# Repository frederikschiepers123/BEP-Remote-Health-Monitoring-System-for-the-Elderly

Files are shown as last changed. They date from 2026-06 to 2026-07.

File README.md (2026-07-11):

# Remote Health Monitoring System for the Elderly

TU Delft BSc Applied Project (BAP). A three-tier system that passively monitors
an elderly person at home — mmWave radar vitals (heart/breath rate, presence),
environment, air quality, light — and delivers the data to a hospital-side
FHIR R4 endpoint, with a smart-mirror UI in the home:

```
┌──────────────────┐   MQTT/mTLS   ┌──────────────────────┐   MQTT/mTLS   ┌──────────────┐   FHIR R4   ┌──────────┐
│  Sensor module   │ ────────────► │  Android tablet      │ ◄──────────── │  SBC         │ ──────────► │ Hospital │
│  Pico 2 W (C11)  │               │  Mosquitto broker    │               │  aggregator  │             │ endpoint │
│  radar/env/air/  │               │  + MagicMirror² UI   │               │  (Python,    │             │ (HAPI in │
│  light + OLED    │               │  behind the mirror   │               │  sbc/)       │             │  dev)    │
└──────────────────┘               └──────────────────────┘               └──────────────┘             └──────────┘
```

Every byte between tiers is mTLS-encrypted (ECDSA P-256, project CA, static
factory-provisioned certs). The firmware publishes raw JSON samples on
`rmms/<uuid>/...`; the mirror and the SBC are independent subscribers of the
same topics.

## Read this first (in order)

1. **[`CLAUDE.md`](CLAUDE.md)** — the firmware + system architecture contract.
   Single source of truth; everything else defers to it.
2. **[`docs/CLAUDE_tablet.md`](docs/CLAUDE_tablet.md)** — the tablet tier
   (broker, MagicMirror², mDNS, presence→screen coupling, autostart).
3. **[`sbc/CLAUDE.md`](sbc/CLAUDE.md)** — the SBC aggregator / FHIR tier.
4. **[`docs/handover.md`](docs/handover.md)** — what is hardware-proven vs
   built-only, known hardware/network gotchas, and CA/cert custody.

## Repository map

| Path | What it is |
|---|---|
| `CLAUDE.md`, `DEMO.md` | The architecture contract and the end-to-end demo runbook (see reading order above / quickstarts below). |
| `main/`, `components/` | **Pico 2 W firmware** (C11; pico-sdk + FreeRTOS + lwIP/mbedTLS + littlefs). One component per concern — layout in `CLAUDE.md §6`. |
| `test/host/` | Native unit tests (CMocka) for driver logic — `bash test/host/run.sh`. |
| `test/bringup/` | Standalone bring-up/diagnostic firmware images (blink → sensors → Wi-Fi → mTLS → full bench). `bringup_sensors` is the demo image. |
| `docs/` | System docs: bring-up procedure, MQTT topic contract, pin map, ADRs, provisioning, handover, technical audit of the previous group's code. |
| `scripts/` | Operational scripts: build, CA + device provisioning, tablet deploy/boot, demo startup, broker ACL test. Index: `scripts/README.md`. |
| `sbc/` | **SBC aggregator** — standalone Python project (own README, RUNBOOK, CLAUDE.md, tests). Never compiled into the firmware. |
| `MagicMirror/` | Vendored upstream MagicMirror² tree (see its README). Project work lives only in `modules/MMM-SensorUI/`, `modules/MMM-CustomMQTTBridge/`, `css/`, `config/` — the live `config.js` holds LAN specifics, is gitignored, and lives on the tablet; `config/config.custom.sample.js` is a UI-only starter. |
| `HealthMonitorWakeTest/` | **Android wake app** (Android Studio project): radar presence ↔ tablet screen on/off via the localhost MQTT listener (ADR-0004). See its README. |
| `apk/` | Prebuilt APK of the wake app. |
| `fully/` | Exported settings for the optional Fully Kiosk Browser (mirror kiosk mode). |
| `third_party/` | Git submodules: FreeRTOS-Kernel, littlefs. **pico-sdk is not vendored** — see the firmware quickstart. |
| `documents_and_diagrams/` | Thesis report, defense presentation, system diagrams. |
| `papers/` | Reference papers + the complete reference list. |
| `lasercutting_files/` | Enclosure/acrylic lasercutting files (DXF + Fusion 360). |
| `PCB/` | This group's KiCad PCB design files + bench measurements (buck converter scope shots). |
| `Readout Code HMMD-MR60BHA2 and BMP/` | Standalone sensor-readout experiments (radar filtering tests, BMP readout) used during bring-up — not part of the production firmware. |

**Local / generated directories (never in git):** `build*/` are CMake output
trees; `out/` is provisioning output created by `scripts/provision_ca.sh` —
it holds device/broker/mirror certificate bundles **including private keys**
and must never be committed (it is gitignored; see `docs/provisioning.md`).
On a fresh clone neither exists until you build/provision.

The **previous BAP group's material** (`bestanden_vorige_BAP/`) was removed
from the tree during handover cleanup — it is reference-only and available in
git history (any pre-July-2026 commit). Their registration protocol was
audited (`docs/technical-audit.md`) and deliberately replaced
(`CLAUDE.md §9.4`); their committed private keys are burned — never reuse
anything cryptographic from that tree.

## Quickstart per tier

### Firmware (Pico 2 W)

```bash
git clone --recurse-submodules <this-repo>            # brings FreeRTOS-Kernel + littlefs
git clone https://github.com/raspberrypi/pico-sdk.git ~/pico/pico-sdk
(cd ~/pico/pico-sdk && git submodule update --init)
export PICO_SDK_PATH=~/pico/pico-sdk

mkdir build && cd build
cmake -DPICO_BOARD=pico2_w -DCMAKE_BUILD_TYPE=Debug ..
cmake --build . -j$(nproc)
# → main/sensor_module.uf2 (production) + test/bringup/*.uf2 (bring-up images)
```

Flash: hold BOOTSEL while plugging in, copy the `.uf2` to the mounted drive
(details + SWD alternative: `CLAUDE.md §5`). Bring-up order with expected
results per step: `docs/bring_up.md`. Host tests: `bash test/host/run.sh`.

### Certificates + device provisioning

Identity is factory-provisioned: certs are generated **off-device** by the
project CA and written to the Pico's littlefs; there is no enrollment protocol
(`CLAUDE.md §9.4`). The full procedure — CA creation, broker/mirror/operator/
device bundles, `bringup_provision.uf2` + `scripts/provision_device.py` — is in
**[`docs/provisioning.md`](docs/provisioning.md)**. The CA private key is *not*
in this repo; custody is covered in `docs/handover.md`.

### Tablet (broker + mirror)

`scripts/deploy_home_kit.sh` provisions/deploys the whole tablet kit over ssh
(Termux); `scripts/tablet_boot.sh` + Termux:Boot make the tablet self-healing
across reboots. Tier spec: `docs/CLAUDE_tablet.md`.

### SBC aggregator (FHIR)

```bash
cd sbc && python3 -m venv .venv && .venv/bin/pip install -e .[dev]
.venv/bin/python -m pytest tests -q
```

Full install/run/prove-the-FHIR-output walkthrough: `sbc/RUNBOOK.md`.

### End-to-end demo

Full session procedure: **[`DEMO.md`](DEMO.md)**. In short:
`scripts/demo_start.sh <tablet-ip>` starts a demo session; a provisioned Pico
running `bringup_sensors.uf2` publishes live sensor data and the mirror renders
it. Networking caveats (use a phone hotspot, not eduroam; keep the tablet
awake) are in `docs/handover.md`.

## Where the contracts live

- MQTT topics + JSON payload schema: `CLAUDE.md §9`, `docs/mqtt_topics.md`.
- Sensor-JSON → FHIR mapping: `CLAUDE.md §9.6` (firmware side) and
  `sbc/docs/fhir-mapping.md` (generated LOINC/UCUM table).
- Mirror UI boundary (raw topics, JS-side thresholds, two-namespace design):
  `CLAUDE.md §9.5`/`§9.5.1` and the module READMEs under `MagicMirror/modules/`.
- Cross-tier loss-tolerance + idempotency: `docs/sbc-failover-and-idempotency.md`.

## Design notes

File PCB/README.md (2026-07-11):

# PCB/

- `PCB Design/` — all KiCad files.
- `Buck_images/` — oscilloscope photos from testing the buck-converter
  circuit on the PCB (directory names give the load condition).

## Which files are authoritative

- **Generic (sensor-module) board:**
  `PCB Design/KiCad files/Generic PCB/Generic PCB/Generic PCB.kicad_pcb`
  (+ matching `.kicad_sch`/`.kicad_pro`). Note the doubled `Generic PCB/`
  nesting is a KiCad project-folder artifact — descend twice.
- **Mirror board:**
  `PCB Design/KiCad files/Mirror PCB/Mrror PCB.kicad_pcb`
  (+ matching `.kicad_sch`/`.kicad_pro`).

Caveats for the next group:

- The `Mrror` spelling is a typo, but it is **load-bearing**: KiCad project
  files cross-reference each other by name — do not rename.
- Some `Mrror PCB*` artifacts (silkscreen PDFs, `Mrror_PCB_routed_v1.kicad_pcb`)
  also sit inside the *Generic* board's folder; the Mirror board's canonical
  files are the ones under `Mirror PCB/`.
- KiCad autosave/backup droppings (`_restore_backup_*`, `*.lck`, `*.bak`,
  `*_chatgpt*.zip`) were deleted at handover and are now gitignored.
- Known board erratum: the I²C bus lacks pull-ups — fit 4.7 kΩ from GP8/GP9
  to 3V3 (see `docs/handover.md`).

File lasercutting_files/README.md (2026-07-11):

# lasercutting_files/

Enclosure/mirror lasercutting sources for the sensor module and the two-way
acrylic mirror front.

- `designing_cuts_acrylic_plates.f3d` — Autodesk Fusion 360 design file (the
  editable source of all cuts).
- `testcuts_radarsensors.dxf` — test cuts, for an acrylic plate of 225×400 mm.
- `finalcut_rounded_rectangle.dxf` — the final cut, for an acrylic plate of
  250×300 mm.

View DXF files without CAD software at <https://dxfviewer.app/>.

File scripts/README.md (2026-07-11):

# scripts/

Operational tooling for the RMMS pipeline — building and provisioning the Pico
sensor module, standing up the Termux tablet tier (Mosquitto broker +
MagicMirror²), and running demos. Each script's header comment is the
authoritative usage doc; this file is only an index.

## Index

| Script | Tier | Purpose |
| --- | --- | --- |
| `build.sh` | firmware | Compile the sensor-module firmware (`build/main/sensor_module.uf2` + `.elf`); optional `--flash` (BOOTSEL) / `--swd` (OpenOCD). Firmware only — no certs, no littlefs content. |
| `provision_ca.sh` | provisioning | Generate the project CA (once) plus broker, mirror, operator, and per-device certs (all ECDSA P-256). CA private key never leaves `$CA_DIR`. |
| `provision_device.py` | provisioning | Push a device bundle (certs + `/cfg` JSON) into the Pico over USB-serial; pairs with the `bringup_provision` UF2, verifies SHA-256 per file, reboots the device. |
| `deploy_home_kit.sh` | provisioning | One-command, idempotent orchestrator for a full home kit (certs → tablet → Pico → SBC), plus a `fleet` mode that loops a TSV manifest. Calls the per-tier tools above. |
| `refresh_broker.sh` | tablet | One-shot broker refresh: re-issue the broker cert for today's tablet IP, scp it to Termux, restart Mosquitto, verify :8883 answers. |
| `setup_tablet_ssh.sh` | tablet | One-time: copy the laptop's SSH public key onto the tablet so `refresh_broker.sh` runs unattended. |
| `tablet_boot.sh` | tablet | Termux:Boot entry point — an Android boot brings up sshd, the broker, the mDNS responder, the presence bridge, and MagicMirror² with no laptop involved. IP-independent and idempotent. |
| `tablet_mdns_responder.py` | tablet | Advertises a stable `tablet.local` name (python-zeroconf, RFC 6762 legacy-unicast) so the Pico finds the broker by name across IP changes. |
| `tablet_presence_screen.py` | tablet | Bridges radar `v.presence` (mTLS `rmms/+/radar`) to the wake/lock app's plain-MQTT `display` topic ("ON"/"OFF") with debounce — screen follows presence. |
| `tablet_start_magicmirror.sh` | tablet | Launches MagicMirror² in server-only mode (`npm run server`), opens Chrome at `localhost:8080`, restarts MM² with backoff if it dies. |
| `demo_start.sh` | demo | One-shot demo bring-up from the laptop: refresh broker cert + restart Mosquitto, start the `tablet.local` mDNS responder, start the radar-presence→screen bridge, refresh the fixed demo-device bundle (first-provision only). MagicMirror runs on the tablet via Termux:Boot — this script does not start it. |
| `test_broker_acl.sh` | demo | Broker mTLS + ACL enforcement harness (7 assertions: own-subtree write, cross-device deny, operator scope, `/cmd` read, anonymous refused). Exit 0 only if all hold. |
| `mock_radxa.py` | SBC | Read-only dev sniffer: subscribe to one device's raw topics, decode the §9.2 envelope, pretty-print values. Its old Radxa-stand-in role is dead — run `sbc/` for real aggregator behaviour. |

`scripts/deprecated/` holds superseded scripts (currently the previous group's
tablet `deploy.sh` and its PDF instructions) — see its own README.

## Typical flows

**Fresh device provisioning**

1. `scripts/provision_ca.sh` — mint (or reuse) the CA and issue the device
   bundle into `out/device-<uuid>/`. For a whole home kit in one go, use
   `scripts/deploy_home_kit.sh` instead — it orchestrates this plus the tablet
   and SBC tiers.
2. Flash the `bringup_provision` UF2, then
   `scripts/provision_device.py /dev/ttyACM0 out/device-<uuid>` to write certs
   and config into littlefs.
3. `scripts/build.sh --flash` (or `--swd`) to build and flash the production
   firmware.

**Demo startup (laptop-driven)**

`scripts/demo_start.sh <tablet-ip>` does the whole session bring-up: broker
cert refresh + Mosquitto restart, `tablet.local` mDNS responder, and the
radar-presence→screen bridge. MagicMirror itself runs on the tablet via
Termux:Boot (`tablet_boot.sh`) and is not started from the laptop. Thanks to
mDNS, the demo Pico is provisioned once and never re-flashed when the IP
changes.

**Tablet self-heal (no laptop)**

`scripts/tablet_boot.sh`, symlinked from `~/.termux/boot/10-rmms`, makes an
Android reboot self-healing: Termux:Boot fires it post-unlock and it restarts
every tablet service, guarded by `pgrep` so double-launches are impossible.
One-time prerequisites (Termux:Boot from F-Droid, battery-optimization off)
are listed in its header.

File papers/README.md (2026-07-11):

- Any references not included in this folder as a pdf (for example websites) are included in the file complete_reference_list.pdf.

- Literature and datasheets about mmwave: Here are the literature about the background study about the using mmwave radar sensors for sensing the vital signs.

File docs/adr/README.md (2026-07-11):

# Architecture Decision Records

Each significant architectural decision is recorded here as a short ADR.

## Format

```
# ADR-NNN: Title

**Status:** Accepted | Superseded by ADR-NNN | Deprecated
**Date:** YYYY-MM-DD

## Context
What forced a decision?

## Decision
What was decided?

## Consequences
What becomes easier or harder?
```

## Index

| # | Title | Status |
|---|---|---|
| [0001](0001-light-sensor-bh1750.md) | Replace GL5516 LDR with Rohm BH1750FVI for ambient light | Accepted |
| [0002](0002-wifi-sole-transport.md) | Wi-Fi is the sole v1 transport — USB-CDC dropped | Accepted |
| [0003](0003-nv-flash-spool-and-time-sync.md) | Non-volatile flash spool + tablet time-sync (lossless uplink) | Accepted |
| [0004](0004-localhost-plain-listener-app-ipc.md) | Localhost-only plain :1883 listener for on-tablet app IPC | Accepted |
| [0005](0005-mcu-side-radar-filtering.md) | MCU-side radar plausibility filtering (supervisor-directed) | Accepted |
| [0006](0006-phase-based-breath-hold-detection.md) | Phase-based breath-hold (apnea) detection (resp_motion) | Accepted |
| [0007](0007-hmmd-radar-second-driver.md) | Second radar driver — Waveshare HMMD 24 GHz behind the v-table | Accepted |
| 0008 | Phase-derived breath rate via Goertzel (no file — see note) | Reverted |
| [0009](0009-led-pin-correction.md) | POWER/WIFI status-LED pins corrected to match the as-built PCB | Accepted |

**ADR-0008 note:** the Goertzel breath-rate estimator landed with commit
`6329d47` and was reverted in `4376965` after bench testing showed it
sub-harmonic-locks to ~half the true rate on real irregular breathing. The
radar's own 0x0A14 breath-rate output is used instead. The number is retired,
not reused; the design and revert rationale live in the git history of those
two commits.

## When to write an ADR

Per CLAUDE.md §4: any new dependency, any change to `board_pico2wh.h`, any new
MQTT topic or command, any change to the security model, or any deviation from
the bring-up order in §15 requires an ADR before the code is written.

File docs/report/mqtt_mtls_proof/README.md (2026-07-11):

# MQTT + mTLS communication — captured proof

Captured 2026-06-21. These logs demonstrate the firmware's MQTT contract
(CLAUDE.md §8.3, §9) and security model (§10) working end to end at the
**protocol level**: mutual-TLS handshake, cert-CN identity, QoS-1 publish/PUBACK,
message delivery to a subscriber, and broker-side ACL enforcement.

## Scope of this capture (read first)

This bundle was produced on the **development host** by running the **real
production broker config** (`out/broker/mosquitto.conf`) with the **real
CA-issued certificates** (`out/`) on the loopback interface, and connecting with
the `mosquitto`/`openssl` clients using the device, mirror and operator certs.

- ✅ Proves: the mTLS trust model, the restricted cipher suite (§10.2),
  `require_certificate`, `use_identity_as_username`, the per-cert ACL, and the
  QoS-1 MQTT round-trip — all with the exact certs and broker policy that ship
  on the tablet.
- ⚠️ Does **not** prove (here): the Pico firmware binary talking to the physical
  tablet over Wi-Fi. That has been demonstrated separately on hardware
  (2026-06-02 `bringup_mqtt.uf2`; 2026-06-19 full PCB e2e on the iPhone hotspot —
  Wi-Fi join, mTLS `CONNACK status=0`, radar vitals publishing). To re-capture
  that live, see "Re-capturing the hardware path" below.

The only differences between `mosquitto-local.conf` and the tablet's
`out/broker/mosquitto.conf` are the cert **paths** (repo `out/` vs Termux home),
the **bind address** (`127.0.0.1` vs `0.0.0.0`), and one extra `log_type
information` line. Auth/TLS/ACL settings are byte-identical.

## Artifacts

| File | What it proves |
|---|---|
| `01_mtls_handshake.log` | Full mutual-TLS handshake as the **device** identity. TLS 1.2, cipher `ECDHE-ECDSA-AES256-GCM-SHA384` (§10.2), `Verify return code: 0 (ok)`, broker chain `tablet.local ← RMMS-Project-CA`, ECDSA peer signature, broker **requested** a client cert (mutual auth). |
| `02_nocert_refused.log` / `02b_nocert_mosquitto.log` | Negative control — a client with **no certificate** is refused (`sslv3 alert handshake failure` / `tlsv13 alert certificate required`). `require_certificate true` enforced. |
| `03_device_publish.log` | Device side of a QoS-1 publish: `CONNECT → CONNACK(0) → PUBLISH(q1) → PUBACK(RC:0)`. |
| `03_mirror_received.log` | Mirror side: the exact §9.2 env JSON delivered over the mirror's own mTLS session. |
| `04_acl_harness.log` | `scripts/test_broker_acl.sh` — **7/7** ACL+mTLS assertions (own-subtree write allowed, cross-device write/read denied, operator info-only, device reads own /cmd, anonymous refused). CLAUDE.md §16-Q9 / bring-up step 12. |
| `broker.stdout.log` | Broker side: each client's MQTT username is its **verified cert CN** (`u'52295a51-…'` = device UUID, `u'mirror-de4ed19a'`, `u'operator-c4c60d23'`) via `use_identity_as_username`; no-cert probes logged as `<unknown> disconnected: Protocol error`. |
| `mosquitto-local.conf` | The localized broker config used for the capture. |

## Reproduce this capture

```bash
# 1. start the broker with the real config + certs on loopback
mosquitto -c docs/report/mqtt_mtls_proof/mosquitto-local.conf -v &

# 2. mTLS handshake as the device
DEV=out/device-52295a51-1a2d-4b2f-bedd-dacbbc1685f0
openssl s_client -connect 127.0.0.1:8883 -CAfile out/broker/ca.crt \
  -cert $DEV/dev.crt.pem -key $DEV/dev.key.pem \
  -verify_ip 127.0.0.1 -verify_return_error \
  -tls1_2 -cipher ECDHE-ECDSA-AES256-GCM-SHA384 </dev/null

# 3. full ACL + mTLS harness
scripts/test_broker_acl.sh 127.0.0.1
```

## Re-capturing the hardware path (Pico → tablet)

When the Pico and tablet are on the same network (phone hotspot — see
project memory; eduroam blocks device↔tablet P2P):

```bash
# device console (TLS handshake → CONNACK → first publish)
minicom -D /dev/ttyACM1 -b 115200          # or: cat /dev/ttyACM1

# on the tablet (or a host with the mirror cert), watch real samples land:
mosquitto_sub --cafile out/broker/ca.crt -h tablet.local -p 8883 \
  --cert out/mirror-*/cert.pem --key out/mirror-*/key.pem \
  -t 'rmms/#' -v
```

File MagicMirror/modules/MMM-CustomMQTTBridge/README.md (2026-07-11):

# MMM-CustomMQTTBridge

Project-internal MagicMirror² module for the TU Delft RMMS (Remote Medical
Monitoring System) BAP project. It is the **adapter between the MQTT wire
contract and the mirror's in-process notification bus**:

- **Wire side** — connects over **mTLS** to the tablet's Mosquitto broker
  (`:8883`) and subscribes to the sensor firmware's raw
  `rmms/<uuid>/<kind>` topics (JSON envelope per root `CLAUDE.md` §9.2).
- **Mirror side** — parses each payload in the `node_helper` and re-broadcasts
  every logical sensor field as an `MQTT_SENSOR_UPDATE` MM² notification with
  payload `{topic: "sensors/<field>", message: "<string>"}`, which
  [`MMM-SensorUI`](../MMM-SensorUI/README.md) consumes.

These are **two deliberately distinct namespaces** (root `CLAUDE.md` §9.5.1):
`rmms/...` is the broker contract shared by the firmware, the Radxa/SBC
aggregator, and the mirror; `sensors/...` exists only inside the MM² process,
between this bridge and MMM-SensorUI. The firmware never emits `sensors/...`;
the tile code never sees `rmms/...` or wire JSON.

> **Repo note:** the surrounding `MagicMirror/` tree is a vendored upstream
> MagicMirror² checkout. Only `modules/MMM-CustomMQTTBridge/`,
> `modules/MMM-SensorUI/`, and the tablet-side `config/` + `css/`
> customisations are project work.

## Single source of truth

This module — specifically the mapping table and dispatch code at the top of
[`node_helper.js`](node_helper.js) — is the **canonical wire→mirror
translation**, referenced by root `CLAUDE.md` §9.5.1. Envelope parsing,
stringification, and null/warm-up handling all live here and nowhere else.
**Adding a new sensor field is a change in exactly one place:** one
`send("name", value)` call in the right `if (kind === ...)` branch of
`node_helper.js`. MMM-SensorUI then only needs a handler for the new
`sensors/<name>` notification; it never touches JSON.

## Configuration

Set in `MagicMirror/config/config.js` (gitignored — the checked-in
`config.js.sample` is the plain upstream sample, not an RMMS example).
Defaults from `MMM-CustomMQTTBridge.js`:

| Key | Default | Meaning |
|---|---|---|
| `broker` | `"mqtts://<tablet-ip>:8883"` | Broker URL. `mqtts://` + all three cert files present ⇒ mTLS; otherwise the bridge falls back to plain MQTT (local mock/test path only). |
| `clientId` | `"mirror-de4ed19a"` | MQTT client ID. **Must match the CN of the mirror certificate** (`mirror-<short-id>`) issued by `scripts/provision_ca.sh` — the broker uses `use_identity_as_username` and its ACL grants the mirror role `topic read rmms/+/+`. |
| `caFile` | `""` | Absolute path to the project CA cert (PEM, from `out/mirror-<id>/`). |
| `certFile` | `""` | Absolute path to the mirror client cert (PEM). |
| `keyFile` | `""` | Absolute path to the mirror private key (PEM). |
| `topics` | `["rmms/+/+"]` | Subscriptions (wildcard covers all devices). |

With TLS active, `rejectUnauthorized: true` is set — server cert validation is
never disabled. The helper keeps **one** MQTT client per process: because the
mirror runs `serveronly`, the browser module re-sends `CONNECT_MQTT` on every
socket reconnect, and without the guard duplicate clients sharing the mirror
`clientId` would kick each other off the broker in a loop.

## Topic → notification mapping

Copied from the canonical table in `node_helper.js`:

| Broker topic + field | Mirror notification | Value (string) |
|---|---|---|
| `rmms/<uuid>/env` · `v.temp_c` | `sensors/temperature` | float, `.toFixed(1)` |
| `rmms/<uuid>/env` · `v.hum_pct` | `sensors/humidity` | int, rounded |
| `rmms/<uuid>/air` · `v.aqi` (1–5) | `sensors/airquality` | UBA label (`Excellent` / `Good` / `Moderate` / `Poor` / `Unhealthy`); `aqi == 0` ⇒ `"WARMUP"` |
| `rmms/<uuid>/air` · `v.co2_ppm` | `sensors/co2` | int |
| `rmms/<uuid>/air` · `v.tvoc_ppb` | `sensors/tvoc` | int |
| `rmms/<uuid>/radar` · `v.heart_bpm` | `sensors/heartrate` | int, rounded; `""` when null |
| `rmms/<uuid>/radar` · `v.breath_bpm` | `sensors/respiratoryrate` | int, rounded; `""` when null |
| `rmms/<uuid>/radar` · `v.resp_motion` | `sensors/respiratorymotion` | `"true"` / `"false"` / `""` (tri-state breath-hold signal, firmware ADR-0006) |
| `rmms/<uuid>/info` · `v.text` | `sensors/infomessage` | text |
| `rmms/<uuid>/status` (raw string, retained) | `sensors/status` | `"online"` / `"offline"` (forwarded for introspection; MMM-SensorUI does not currently display it) |
| `rmms/<uuid>/light` | — | intentionally ignored in v1 |
| `rmms/<uuid>/log` | — | intentionally ignored (not sensor data) |
| `rmms/<uuid>/screen` | — | not mapped in the current code (the operator page-select topic from `CLAUDE.md` §9.5 is not wired through this bridge yet) |

Topics that don't match the `rmms/<uuid>/<kind>` shape are relayed **verbatim**
(topic + raw string), so legacy `sensors/...` test publishers keep working
against local mock setups.

## Null / quality / warm-up handling

What the code actually does:

- **Radar nulls clear the tile.** Firmware vitals are presence-gated: a `null`
  `heart_bpm` / `breath_bpm` means "no presence-confirmed reading". The bridge
  forwards `null` as an **empty string**, which MMM-SensorUI treats as
  "no value" ("Measuring..."), instead of freezing the last number after the
  person walks away. `resp_motion` `null`/absent likewise becomes `""`
  (undetermined — clears any hold state; old firmware without the field is
  therefore harmless).
- **ENS160 warm-up.** Only `aqi == 0` (no usable reading yet) is shown as
  `"WARMUP"`. Readings with `aqi >= 1` are forwarded even while the chip still
  flags `INITIAL_STARTUP` (envelope `q=2`, up to ~1 h) — those values are
  already meaningful.
- **Envelope `q` flag.** Beyond the AQI case above, the current code does
  **not** inspect the envelope's `q` quality field; the firmware itself nulls
  degraded vitals, and that nulling is what the bridge forwards. If `q`-based
  gating is ever needed on the mirror, it belongs **here**, not in
  MMM-SensorUI (per §9.5.1). Note from field experience: gating presence
  behaviour on `distance != null` is more robust than gating on `q`.
- **Non-JSON payloads** on an `rmms/...` topic are logged and dropped.
- The parser tolerates both the `{"ts_us":..., "v":{...}}` envelope and a flat
  object (`env.v || env`).

## Files

- `MMM-CustomMQTTBridge.js` — browser-side module: sends `CONNECT_MQTT` with
  the config, relays `MQTT_SENSOR_UPDATE` onto the MM² notification bus, and
  shows the last message / bridge status as a small debug DOM (header
  "MQTT bridge").
- `node_helper.js` — Node-side: MQTT (m)TLS client, subscription, JSON
  parsing, the canonical mapping table.
- Depends on the `mqtt` npm package (see `package.json`).

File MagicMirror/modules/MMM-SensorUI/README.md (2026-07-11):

# MMM-SensorUI

Project-internal MagicMirror² module for the TU Delft RMMS (Remote Medical
Monitoring System) BAP project. It renders the smart-mirror UI behind the
two-way acrylic: **per-sensor tiles with numeric values and a traffic-light
severity indicator** (`green` / `yellow` / `red`), plus an operator info panel
and a "last updated" footer.

> **Repo note:** the surrounding `MagicMirror/` tree is a vendored upstream
> MagicMirror² checkout. Only `modules/MMM-SensorUI/`,
> `modules/MMM-CustomMQTTBridge/`, and the tablet-side `config/` + `css/`
> customisations are project work.

## Data source — `sensors/*` notifications only

This module consumes **only** `MQTT_SENSOR_UPDATE` MM² notifications with
payload `{topic: "sensors/<field>", message: "<string>"}`, produced by
[`MMM-CustomMQTTBridge`](../MMM-CustomMQTTBridge/README.md). It **never**
connects to MQTT, never parses wire JSON, and knows nothing about the
`rmms/<uuid>/...` topic tree, the §9.2 envelope, or the `q`/`wall_ms`/`seq`
fields — that translation lives entirely in the bridge (root `CLAUDE.md`
§9.5.1). All values arrive as pre-stringified messages; an **empty string
means "no value"** and clears the tile back to "Measuring...".

Handled notifications: `sensors/heartrate`, `sensors/respiratoryrate`,
`sensors/respiratorymotion`, `sensors/temperature`, `sensors/humidity`,
`sensors/airquality`, `sensors/infomessage`. (`sensors/co2` and
`sensors/tvoc` only refresh the internal environment timestamp; they have no
tile. `sensors/status` is forwarded by the bridge but not handled here.)

## Tiles

| Tile | Notification | Display |
|---|---|---|
| Heart rate | `sensors/heartrate` | number + "BPM" + severity icon |
| Breath rate | `sensors/respiratoryrate` + `sensors/respiratorymotion` | number + "breaths per min" + severity icon. When `respiratorymotion == "false"` (confirmed breath-hold, firmware ADR-0006), the tile shows **"No breathing"** in red instead — the hold overrides the (firmware-suppressed) rate. |
| Temperature | `sensors/temperature` | number + "°C" + severity icon |
| Humidity | `sensors/humidity` | number + "%" + severity icon |
| Air quality | `sensors/airquality` | text label only (UBA label from the bridge, e.g. "Good", or "WARMUP") + severity icon — no number |
| Info panel | `sensors/infomessage` | operator text message (from `rmms/<uuid>/info` via the bridge), shown above the footer timestamp |
| Footer | — | "Vitals last updated: HH:MM:SS" — timestamp of the last non-empty vitals message, persisted in `localStorage` so a kiosk page reload restores it. An environment timestamp is tracked internally but not rendered. |

Vitals tiles are independent: an absent heart or breath value shows a
per-tile "Measuring..." card without blanking the other; only when both are
absent (and no breath-hold is active) do they collapse into one combined
"Measuring..." panel. The environment row does the same when any of
temperature / humidity / air quality is missing.

**Not implemented in this module version:** the `sensors/status`
online/offline footer and the `screen.v.page` layout switching (pages 1–4)
described in root `CLAUDE.md` §9.5. The bridge forwards `sensors/status`, but
this module ignores it, and the `rmms/<uuid>/screen` topic is not mapped by
the bridge at all.

## Severity thresholds (as coded)

The traffic-light logic lives in `THRESHOLDS` / `AIR_QUALITY_STATUS` at the
top of `MMM-SensorUI.js`. A value inside the `green` range is green; else
inside the `yellow` range is yellow; else **red**. Empty or non-numeric values
get no severity (never render red).

| Measure | Green | Yellow | Red |
|---|---|---|---|
| Heart rate (BPM) | 60–100 | 50–110 | otherwise |
| Respiratory rate (breaths/min) | 12–20 | 10–24 | otherwise |
| Temperature (°C) | 20–24 | 18–27 | otherwise |
| Humidity (%) | 40–60 | 30–70 | otherwise |

Air quality maps the UBA label directly:
`Excellent`/`Good` → green, `Moderate` → yellow, `Poor`/`Unhealthy` → red,
anything unrecognised (including `"WARMUP"`) → red.

> **Handover warning:** root `CLAUDE.md` §9.5 requires each threshold range to
> carry a comment citing its source (WHO, AHA, ASHRAE, ...) and clinical
> advisor sign-off before any deployment beyond the project review. **The
> ranges above currently have no citations in the code.** Do not treat them
> as clinically validated; obtain sign-off (and add the citations) before real
> deployment. Note also that §9.5 specifies four severity levels including
> `orange`; the code implements three (`green`/`yellow`/`red`).

## Configuration

`defaults` is empty (`{}`) — there are **no config.js keys**. Behaviour is
tuned via constants at the top of `MMM-SensorUI.js`:

- `DISPLAY_MODE` — `"icons"` (default: severity shown as a check /
  exclamation / warning-triangle icon under the value) or `"colors"`
  (severity colours the value text instead).
- `THRESHOLDS`, `AIR_QUALITY_STATUS` — the tables above.

Styling is in `MMM-SensorUI.css` (viewport-relative sizing, tile wrappers,
severity colours `#4CAF50` / `#FFC107` / `#F44336`, "Measuring..." layouts).
Requires Font Awesome (loaded via MagicMirror's bundled `font-awesome.css`).

## Adding a new field

Per §9.5.1: add the wire→string translation as one `send(...)` call in the
bridge's `node_helper.js`, then add a `sensors/<name>` handler and tile here.
Derived UI values are computed **here** (mirror-side JS), never in the
firmware; new raw topics require a new sensor on the board.

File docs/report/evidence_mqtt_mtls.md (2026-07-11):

# Evidence Appendix — MQTT Message Protocol & mTLS

This appendix collects reproducible exhibits backing the communication-and-security
claims. Every exhibit is either a committed source/config file or the verbatim
output of a command you can re-run. File paths are clickable in the repo.

---

## A. Transport & message protocol (what the firmware speaks)

- **MQTT v3.1.1** client (lwIP `pico_lwip_mqtt`) running **over `altcp_tls`
  (mbedTLS)** — there is no plaintext MQTT path off the device. Single owner:
  `components/transport_mqtt/transport_mqtt.c`.
- **Per-device topic tree** `rmms/<uuid>/...`; the device UUID is also the MQTT
  `client_id`:
  - `transport_mqtt.c:508` — `s_ci.client_id = s_id->uuid;`
- **Publish QoS 1** for every sensor sample (retry-until-PUBACK from the spool):
  - `transport_mqtt.c:693` — `mqtt_publish(..., /*qos=*/1, /*retain=*/0, ...)`
- **Retained status + Last-Will-and-Testament**, both QoS 1:
  - `transport_mqtt.c:395` — `"online"` published `qos=1, retain=1` on CONNACK
  - `transport_mqtt.c:511-514` — LWT `rmms/<uuid>/status = "offline"`, `qos=1, retain=1`
- **Subscribes only to its own downlinks** — `rmms/<uuid>/cmd` and
  `rmms/<uuid>/time/set` (`transport_mqtt.c:400`). It never subscribes to other
  devices' trees.
- **Payload = compact JSON** per the §9.2 envelope (`ts_us`, `wall_ms`, `seq`,
  `q`, `v{...}`); schema in [docs/mqtt_topics.md](../mqtt_topics.md).

> Claim you can defend: *"The device speaks MQTT 3.1.1 exclusively over mutual
> TLS, publishes each vitals sample at QoS 1 into its own `rmms/<uuid>/...`
> subtree, advertises liveness with a retained online/offline LWT, and
> subscribes only to its own command/time topics."*

---

## B. Mutual TLS (both directions, static factory certs)

### B.1 The firmware does *two-way* auth, not server-only TLS
`components/transport_mqtt/transport_mqtt.c:482`:

```c
s_tls_cfg = altcp_tls_create_config_client_2wayauth(
    /* CA */ ca, ca_len,        /* validate the broker against the project CA */
    /* key */ key, key_len,     /* present the device private key ... */
    /* cert */ crt, crt_len);   /* ... and the device cert (client auth) */
```

`..._2wayauth` = the device **presents its own cert** *and* **validates the
broker's cert against the same project CA**. Mutual authentication, single trust
anchor.

### B.2 TLS profile is locked to ECDHE-ECDSA P-256 / AES-GCM
[mbedtls_config.h](../../mbedtls_config.h) — `MBEDTLS_SSL_PROTO_TLS1_2` only;
ECDHE-ECDSA key exchange; P-256 only; AES-128/256-GCM; SHA-256/384.
RSA, DHE, CBC, RC4, DES, SHA-1 are all `#undef`-ed.

> **Calibration — important for the defense:** the **device negotiates TLS 1.2**,
> not 1.3. pico-sdk 2.x does not compile the mbedTLS 1.3 handshake sources, so
> 1.3 is deliberately disabled (comment at `mbedtls_config.h:21-27`). Any
> "TLS 1.3" seen in broker logs is a **desktop** client (mirror/operator/
> `mosquitto_pub`, which default to 1.3), **not the Pico**. State the device path
> as **"TLS 1.2, ECDHE-ECDSA-AES128/256-GCM-SHA256/384, mutual auth, P-256."**

### B.3 The certificates are real ECDSA P-256, CN = UUID, signed by the project CA
Verbatim `openssl` output (re-run: `openssl x509 -in <cert> -noout -text`):

```
### CA cert
subject=CN = RMMS-Project-CA
issuer=CN = RMMS-Project-CA           <- self-signed root
ASN1 OID: prime256v1 / NIST CURVE: P-256
Signature Algorithm: ecdsa-with-SHA256
CA:TRUE, pathlen:0

### Device cert
subject=CN = 7b3728e2-e682-4d08-90ca-48757d9ecc5a   <- CN *is* the device UUID
issuer=CN = RMMS-Project-CA                          <- signed by project CA
ASN1 OID: prime256v1 / NIST CURVE: P-256
Signature Algorithm: ecdsa-with-SHA256
X509v3 Extended Key Usage: TLS Web Client Authentication
SAN: URI:urn:rmms:device:7b3728e2-e682-4d08-90ca-48757d9ecc5a

### Chain verification
out/device-7b3728e2-.../dev.crt.pem: OK              <- chains to the CA
```

Provisioning script: [scripts/provision_ca.sh](../../scripts/provision_ca.sh)
(generates CA + device/mirror/operator certs, all P-256, off-device).

---

## C. Broker maps cert CN → identity → per-device authorization

Broker config [out/broker/mosquitto.conf](../../out/broker/mosquitto.conf) —
the only network-facing listener:

```
listener 8883 0.0.0.0
allow_anonymous false
require_certificate true          # no cert -> no connection
use_identity_as_username true     # MQTT username := cert CN
acl_file .../acl
```

ACL [out/broker/acl](../../out/broker/acl) — `%u` is the CN-derived username:

```
pattern write rmms/%u/#           # a device may publish ONLY under its own UUID
pattern read  rmms/%u/cmd         # ... and read ONLY its own /cmd
user mirror-de4ed19a
  topic read  rmms/#              # mirror: read-only across the whole tree
user operator-c4c60d23
  topic write rmms/+/info         # operator: write ONLY info/screen
  topic write rmms/+/screen
```

> Claim you can defend: *"The broker requires a client certificate, derives the
> MQTT username from the certificate CN, and a pattern ACL confines each device
> to publishing within its own `rmms/<uuid>/#` subtree and reading only its own
> `/cmd`."*

---

## D. ACL-enforcement test harness (positive + partial negative)

[scripts/test_broker_acl.sh](../../scripts/test_broker_acl.sh) makes **7
assertions** against the live broker. Because Mosquitto silently drops
ACL-denied publishes, it asserts via a privileged mirror observer (it checks
whether a publish actually *lands*, not the subscribe ACK):

| # | Assertion | Type |
|---|---|---|
| A | device → own subtree **allowed** | positive |
| B | device → *other* device subtree **denied** | **negative (cross-device write isolation)** |
| C | operator → `/info` **allowed** | positive |
| D | operator → `/env` **denied** (operator is info/screen-only) | **negative (role confinement)** |
| E | device reads its own `/cmd` **allowed** | positive |
| F | device → read *other* device's topics **denied** | **negative (cross-device read isolation)** |
| G | anonymous / **no client cert** connection **refused** | **negative (require_certificate)** |

> **Calibration vs. the current report draft:** the harness already covers
> cert-less refusal (G) and cross-device read+write isolation (B, F). So you can
> claim *more* negative testing than "not completed." The one negative case
> genuinely **missing** is **rogue-CA rejection** (a cert signed by a *different*
> CA) — see §F to close it.

---

## E. Live captures to attach (run against the running tablet broker)

These need the tablet broker up (`scripts/demo_start.sh`). Each produces a
paste-ready artifact for the report.

1. **ACL harness result (7/7):**
   ```
   scripts/test_broker_acl.sh <tablet-ip>
   ```
   Attach the `=== N passed, 0 failed ===` block.

2. **Broker log showing mTLS + CN-as-username + per-client connect** (Termux):
   ```
   mosquitto -c .../mosquitto.conf -v   # already verbose in demo_start
   ```
   Capture the lines: `New client connected ... as <uuid>` and the TLS/cipher
   notice. This is the "confirmed from broker logs" evidence.

3. **Independent handshake proof (cipher + peer chain), device profile:**
   ```
   openssl s_client -connect <tablet-ip>:8883 -tls1_2 \
       -CAfile ~/rmms-ca/ca.crt \
       -cert out/device-<uuid>/dev.crt.pem -key out/device-<uuid>/dev.key.pem 2>/dev/null \
       | grep -E 'Protocol|Cipher|subject=|issuer='
   ```
   Expect `Protocol: TLSv1.2`, an `ECDHE-ECDSA-AES*-GCM-SHA*` cipher, and the
   broker cert chaining to `RMMS-Project-CA`.

4. **Live message capture (the actual protocol on the wire):**
   ```
   mosquitto_sub --cafile ~/rmms-ca/ca.crt -h <tablet-ip> -p 8883 \
       --cert out/mirror-de4ed19a/cert.pem --key out/mirror-de4ed19a/key.pem \
       -t 'rmms/#' -v
   ```
   Attach a few `rmms/<uuid>/env|radar|... {json}` lines + the retained
   `rmms/<uuid>/status online`.

---

## F. Optional: close the rogue-CA gap in ~5 minutes

This makes the negative-testing claim complete. Generates a throwaway CA + cert
and proves the broker rejects it:

```bash
TMP=$(mktemp -d)
openssl ecparam -name prime256v1 -genkey -noout -out $TMP/rogue-ca.key
openssl req -x509 -new -key $TMP/rogue-ca.key -days 1 -subj /CN=ROGUE-CA -out $TMP/rogue-ca.crt
openssl ecparam -name prime256v1 -genkey -noout -out $TMP/rogue.key
openssl req -new -key $TMP/rogue.key -subj /CN=11111111-1111-1111-1111-111111111111 -out $TMP/rogue.csr
openssl x509 -req -in $TMP/rogue.csr -CA $TMP/rogue-ca.crt -CAkey $TMP/rogue-ca.key \
    -days 1 -out $TMP/rogue.crt
# Present the rogue cert to the real broker — expect connection REFUSED:
mosquitto_pub --cafile ~/rmms-ca/ca.crt -h <tablet-ip> -p 8883 --insecure \
    --cert $TMP/rogue.crt --key $TMP/rogue.key \
    -t rmms/11111111-1111-1111-1111-111111111111/x -m nope \
  && echo "BREACH: rogue cert accepted" || echo "PASS: broker rejected rogue-CA cert"
```

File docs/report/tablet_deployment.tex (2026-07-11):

% ============================================================================
% Tablet Deployment — report section + appendix
% ----------------------------------------------------------------------------
% Preamble requirement: \usepackage{listings}
% MagicMirror^2 uses \textsuperscript{2} (swap for $^2$ if your template prefers).
%
% This file contains TWO blocks:
%   1. MAIN TEXT  — a short \subsection for the body of the report.
%   2. APPENDIX   — the detailed procedure; place it after \appendix.
% The cross-reference resolves automatically once both are included.
% ============================================================================

% ============================== 1. MAIN TEXT ================================
\subsection{Tablet Deployment Script}
\label{sec:tablet-deployment}

The tablet --- which hosts both the system's MQTT broker and the
MagicMirror\textsuperscript{2} interface --- is provisioned by a single on-device
script (\texttt{deploy.sh}) that installs the broker, the
MagicMirror\textsuperscript{2} interface and the supporting services, and registers
them to start automatically whenever the tablet boots. A second, short step run
from the workstation then delivers the tablet's mutual-TLS certificates, which for
security reasons are never generated on the device itself. The full procedure and
its design rationale are described in Appendix~\ref{app:tablet-deploy}.

% ============================== 2. APPENDIX =================================
% Place this after \appendix in your report.
\section{Tablet Deployment Procedure}
\label{app:tablet-deploy}

Provisioning the tablet is more involved than a conventional Linux service
installation for two reasons. First, Android is a difficult host for unattended
background services: it has no service manager, applies aggressive power management
(Doze), and may terminate background processes under memory pressure. Second, the
system's security model forbids the project's certificate-authority (CA) private
key from ever residing on the tablet. The procedure below is shaped by these two
constraints.

\subsection{A two-stage procedure}

Provisioning is split into an on-device stage and a workstation stage. The
on-device stage is a single, idempotent script (\texttt{deploy.sh}) run once inside
Termux from a clone of the project repository; it installs and configures
everything that can be done locally on the tablet. The workstation stage then runs
from the developer laptop and pushes the tablet's mutual-TLS identity --- its broker
and mirror certificates together with the broker configuration --- onto the device
over SSH. This split follows directly from the security model: the CA private key
is the root of trust for the entire device fleet, so it must not be placed on an
always-on, physically accessible tablet. The tablet therefore receives only its own
leaf certificates and the public CA certificate, and the on-device script handles
no secret material.

\subsection{On-device provisioning (\texttt{deploy.sh})}

The script is idempotent (safe to re-run) and performs the following:
\begin{enumerate}
  \item Requests storage access and updates the Termux package index.
  \item Installs the required packages:
    \begin{itemize}
      \item \textbf{Git, Node.js} --- MagicMirror\textsuperscript{2} and its installer;
      \item \textbf{Mosquitto} --- the MQTT broker;
      \item \textbf{OpenSSH} --- remote access for the workstation stage;
      \item \textbf{Python} with the \texttt{zeroconf} and \texttt{paho-mqtt}
            libraries --- the mDNS responder and the presence-to-screen bridge;
      \item the \textbf{Termux:API} tools --- the wake-lock and the commands used
            to launch the kiosk browser.
    \end{itemize}
  \item Installs MagicMirror\textsuperscript{2} and the MQTT-client dependency of
        the custom bridge module. Because the script runs from a Git checkout,
        MagicMirror's installer --- which performs a clean-up step and fetches its
        bundled front-end assets --- completes correctly.
  \item Copies the runtime scripts into place and installs \texttt{tablet\_boot.sh}
        as the Termux:Boot hook.
  \item Starts the SSH daemon and prints the tablet's address together with the
        command to run on the workstation.
  \item Stages the kiosk-browser configuration and the companion Android
        application in the Downloads folder for installation.
\end{enumerate}
Until the certificates are delivered by the workstation stage, the mirror interface
loads but the broker remains down; this is intentional, as the broker cannot start
without its key material and the system does not fall back to an insecure mode.

\subsection{Self-healing autostart (\texttt{tablet\_boot.sh})}

Because Android offers no service manager, persistence is achieved with the
\emph{Termux:Boot} add-on, which runs a hook script after the device boots and is
first unlocked. On each boot the hook executes, in order: acquire a wake-lock (to
survive Doze); wait for Wi-Fi association; start the SSH daemon; start Mosquitto
(once its certificates are present); start the mDNS responder; start the
presence-to-screen bridge; and start MagicMirror\textsuperscript{2} with its kiosk
viewer. Each service is guarded so that re-running the hook never starts a
duplicate, and the mirror launcher restarts the interface with exponential back-off
on failure, so the tablet recovers from a reboot or power interruption without
intervention.

\subsection{Network-independent broker discovery}

The sensor modules must locate the broker without hard-coded addresses, as the home
network assigns IP addresses dynamically. The tablet advertises itself over
multicast DNS under the stable name \texttt{tablet.local}; each sensor module is
provisioned once with this name and resolves the current address at every
connection. The installation therefore tolerates address changes and network moves
without any re-provisioning of the sensor devices.

\subsection{Manual steps (Android restrictions)}

A few actions cannot be automated because of Android's security model and must be
performed once by the installer:
\begin{itemize}
  \item Disable battery optimisation for Termux (otherwise Doze suspends the services).
  \item Install the Termux:Boot add-on (from F-Droid).
  \item Unlock the device once after boot to arm the hook (it fires only after the
        first unlock).
  \item Import the kiosk-browser configuration and install the companion
        application when Android prompts.
\end{itemize}

\subsection{Summarised procedure}

\begin{lstlisting}[
  basicstyle=\ttfamily\small,
  breaklines=true,
  frame=single,
  captionpos=b,
  caption={Tablet deployment commands.},
  label={lst:tablet-deploy}]
On the tablet (once, in Termux):
  1.  pkg install -y git
  2.  git clone <repository-url>
  3.  cd <repository> && ./deploy.sh

On the workstation (once):
  4.  scripts/setup_tablet_ssh.sh        <tablet-ip>
  5.  scripts/deploy_home_kit.sh tablet  <home-id> <tablet-ip>

Manual Android steps (once): disable battery optimisation for Termux,
install Termux:Boot, unlock after boot, import the kiosk configuration.
\end{lstlisting}

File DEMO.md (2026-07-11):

# Running the end-to-end demo

The live demo: a provisioned Pico publishes real sensor data (radar vitals,
env, air, light) over Wi-Fi + mTLS to the tablet's Mosquitto broker, and the
MagicMirror² behind the acrylic renders the tiles. Total setup ≈ 1 minute once
the parts have been provisioned.

## Prerequisites (one-time)

1. A provisioned Pico — certs + `/cfg` in littlefs (`docs/provisioning.md`),
   flashed with `bringup_sensors.uf2` (or `bringup_sensors_slow.uf2`, the
   same image at a 100 kHz I²C clock, for boards with marginal bus wiring).
   Both include the 7 OLED troubleshooting pages.
2. A deployed tablet — broker + MagicMirror² + wake app via
   `scripts/deploy_home_kit.sh`; reboot-proof through Termux:Boot
   (`scripts/tablet_boot.sh`).
3. A **phone hotspot** for networking. Not eduroam — it blocks
   client-to-client traffic. On an iPhone, keep *Maximize Compatibility* ON.

## Each session

```bash
scripts/demo_start.sh <tablet-ip> [device-uuid]
```

That refreshes the broker cert for today's IP, starts the `tablet.local`
mDNS responder, and starts the radar-presence→screen bridge — see the script
header for the fixed-demo-UUID note. The mirror itself runs **on the tablet**
via Termux:Boot (`scripts/tablet_boot.sh`); if it's down, restart it there,
not from the laptop. Then power the Pico. Because the device resolves the
broker by name (`tablet.local`), a changed hotspot IP needs **no
re-provisioning and no reflash**.

Watch raw data with the mirror cert if needed (the operator cert cannot —
its ACL is write-only for `info`/`screen`):

```bash
mosquitto_sub -h <tablet-ip> -p 8883 --cafile out/broker/ca.crt \
  --cert out/mirror-<id>/cert.pem --key out/mirror-<id>/key.pem \
  -t 'rmms/+/+' -v
```

## If something doesn't come up

Work the table in `docs/handover.md` ("known hardware gotchas") — it covers
every failure this group actually hit: hotspot join gating, tablet Doze
killing the broker, radar distance limits, ghost presence from a wall, I²C
pull-ups, ENS160 warm-up. The OLED troubleshooting pages
(`bringup_sensors_slow`) show link state and per-sensor health on-device.

The June 2026 supervisor-demo snapshot this file replaced is archived at
`docs/archive_demo_2026-06.md`.

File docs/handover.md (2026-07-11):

# Handover — project state, verification status, and known gotchas

Written at project end (July 2026) for the supervisor and the next group.
This is the honest ledger of what is *proven on hardware*, what is *built but
not hardware-verified*, and the operational traps that cost this group bench
time. Architecture questions belong in `CLAUDE.md`; this file is about state.

## What is proven on real hardware

- **End-to-end secure pipeline** — Pico 2 W → Wi-Fi → mTLS (ECDSA P-256) →
  Mosquitto on the tablet → MagicMirror² tiles, with live radar vitals
  (heart/breath), presence/distance, AHT21 env, ENS160 air quality, BH1750
  lux. Demonstrated repeatedly with the `bringup_sensors` /
  `bringup_sensors_slow` images (the demo firmware).
- **MR60BHA2 radar driver** — Seeed SOF-`0x01` framing, checksums, vitals
  decode, plus the MCU-side plausibility filtering (ADR-0005,
  `docs/radar_filtering_explained.md`). Heart-rate offset validated against a
  pulse oximeter.
- **SH1122 OLED** — driver + 7-page render path, used in every demo.
- **Broker ACL** — `scripts/test_broker_acl.sh`: 7/7 assertions against the
  live tablet broker (`CLAUDE.md §16 Q9`); evidence: `docs/report/evidence_mqtt_mtls.md` + the captured logs in `docs/report/mqtt_mtls_proof/`.
- **Tablet self-heal** — reboot-proof stack via Termux:Boot →
  `scripts/tablet_boot.sh` (broker, sshd, MagicMirror, wake app), IP-independent
  thanks to mDNS (`tablet.local`).
- **Presence → screen coupling** — radar presence wakes/locks the tablet
  screen (wake app + `scripts/tablet_presence_screen.py`, ADR-0004).
- **SBC aggregator** — full pipeline against throwaway SQLite + HAPI FHIR in
  Docker per `sbc/RUNBOOK.md`; 68 tests green (28 pure + 16 unit + 24
  integration). Not soak-tested on the real ROCKPro64 for extended periods.

## Built and unit-tested, but NOT hardware-verified end-to-end

- **The production firmware image** (`sensor_module.uf2`: `app_main` +
  `transport_task` + NV flash spool + watchdog). It builds, host tests pass
  (56), and it shares its entire driver/transport code with the proven
  bring-up images — but the demos ran `bringup_sensors`, and the production
  image has not had its own long soak (spool drain across outages, watchdog
  behaviour, 48 h run per `CLAUDE.md §14.3`). **This is the first thing the
  next group should verify.**
- **Waveshare HMMD radar driver** (`radar_hmmd.c`, ADR-0007) — protocol
  implemented from the previous group's working reference + host tests; not
  exercised against a live HMMD module by this group.
- **DFRobot C1001 radar** — pins wired in `board_pico2wh.h`, driver *not
  written* (was in development; the v-table seam is the extension point).

## Known hardware gotchas (each cost real bench time)

| Symptom | Cause / fix |
|---|---|
| All I²C sensors dead on the PCB (fine on a bare Pico) | PCB I²C bus lacks pull-ups — fit **4.7 kΩ from GP8/GP9 to 3V3**. |
| ENS160 reads all zeros forever | Driver used to re-kick OPMODE after 2 STATAS=0 reads, restarting a genuinely-warming chip in a loop. Fixed (debounce 15); if you see it again, use `bringup_ens160_diag`. ENS160 also legitimately needs ~5–10 min warm-up (`q=2` meanwhile). |
| `breath_bpm` stuck at 0 while heart rate works, checksum errors every ~5–10 s | Marginal radar UART/GND wiring — reseat TX/RX/GND/5V. |
| Breath rate won't drop below ~high-teens | Subject too far: chest-motion SNR needs **≤ ~0.7 m**. Under **0.35 m** the distance gate blanks all vitals — there is a floor *and* a ceiling. |
| `presence:true, distance:null, q:2` with nobody there; screen never sleeps | A wall ~2.5 m in the radar cone is a ghost target. Clear the field, or gate on `distance_mm != null` (the presence bridge currently gates on raw presence — see `HealthMonitorWakeTest/README.md`). |
| Device joins Wi-Fi only after ~5 retries (`rc=-8`) | Some routers do this transiently — the firmware retries 15–20×; not a bug. On an iPhone hotspot, `rc=-2` stuck at "joining" = hotspot is gating new joins: open the hotspot UI, enable *Maximize Compatibility*. |
| Device ↔ tablet can't talk on campus | eduroam blocks client-to-client traffic. **Use a phone hotspot for demos.** |
| Broker/sshd die mid-demo, hotspot IP drifts | Android Doze when the tablet sleeps. Keep the tablet awake (the wake app / presence coupling handles the screen; the tablet must stay powered and un-dozed). |
| Mirror font/layout reverts after a tablet re-setup | `config/custom.css` + Tiresias font are gitignored by upstream MagicMirror; `scripts/deploy_home_kit.sh` now pushes them on every deploy. |

## Environment sensor: it is a BMP280

The env footprint part long documented as "BME280" is a **BMP280** (chip ID
`0x58`): temperature + pressure, **no humidity**. The firmware, config value
(`"bmp280"`, legacy `"bme280"` accepted), wire schema (`hum_pct: null`) and
SBC decoder all reflect this now. The AHT21 (temp + humidity, no pressure) is
the other populate option; the demo board runs an AHT21 (its provisioned
`/cfg/sensors.json` says `"env":"aht21"` — confirm via the `bringup_provision`
LIST command; note a naive re-provision would write the `"bmp280"` default).

## Credentials and CA custody — action required at handover

- The **project CA private key** lives only in `~/rmms-ca/` on the departing
  student's provisioning workstation. It is not in this repo, by design.
  Transfer or regenerate per **`docs/provisioning.md §4`** — until then the
  next group cannot issue any certificates.
- Deployed artifacts (broker certs on the tablet, device bundles in `out/`)
  are LAN-specific and gitignored; regenerate per `docs/provisioning.md`.
- Leaf certs expire **2 years** after issue (`LEAF_DAYS=730`); the CA after
  10 years. Devices provisioned mid-2026 need re-provisioning mid-2028.

## Open items inherited by the next group

1. Hardware-verify + 48 h soak the production `sensor_module` image (above).
2. Fit the PCB I²C pull-ups properly (board rev or rework).
3. Clinical sign-off on the mirror severity thresholds — the ranges in
   `MMM-SensorUI.js` carry no citations yet (`CLAUDE.md §9.5` requires them
   before any deployment beyond the project review).
4. C1001 radar driver behind the `radar_driver_t` v-table (pins already wired).
5. SBC: real-hospital OAuth (SMART backend services JWT path) — dev path uses
   HAPI without auth; and the placeholder codes flagged `confirmed=False` in
   `sbc/src/rmms_aggregator/fhir/codes.py` need clinical LOINC/SNOMED
   assignment.
6. CLAUDE.md `§16` Q7/Q8 are operationally answered in `docs/provisioning.md`;
   fold them into §16 as resolved once the CA transfer actually happens.

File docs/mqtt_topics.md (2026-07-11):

# MQTT Topic and Payload Schema

**Reference for the topics published or subscribed to by the sensor-module
firmware.** The authoritative contract is root `CLAUDE.md §9.1` (topics) and
`§9.2` (JSON payloads); `§9.6` covers the firmware→SBC FHIR mapping. This file
mirrors those sections for quick reference — if it ever drifts, the root file
wins.

All topics are rooted at `rmms/<uuid>/...` where `<uuid>` is the factory-provisioned
device UUID (36-character UUIDv4 string). **Payloads are JSON** (RFC 8259, UTF-8,
compact). CBOR was considered and rejected (root `CLAUDE.md §9.2`). All uplink
sensor topics are delivered at-least-once with QoS-1 retry from the device's
non-volatile flash spool ([ADR-0003](adr/0003-nv-flash-spool-and-time-sync.md)),
so a message may be delayed or re-sent after an outage — consumers dedup on `seq`.

---

## Topic table

| Topic | Direction | QoS | Retained | Notes |
|---|---|---|---|---|
| `rmms/<uuid>/env` | publish | 1 | no | Environment sample (BMP280 or AHT21) |
| `rmms/<uuid>/air` | publish | 1 | no | Air-quality sample (ENS160) |
| `rmms/<uuid>/radar` | publish | 1 | no | Radar sample (raw + quality flag) |
| `rmms/<uuid>/light` | publish | 1 | no | Light sample (BH1750 or GL5516) |
| `rmms/<uuid>/status` | publish | 1 | **yes** | `"online"` / `"offline"` (LWT) |
| `rmms/<uuid>/cmd` | subscribe | 1 | — | Commands (see below) |
| `rmms/<uuid>/time/set` | subscribe | 1 | — | Wall-clock sync `{"epoch_ms":…}` (§9.2.5; ADR-0003) |
| `rmms/<uuid>/log` | publish | 0 | no | Critical log lines (text, best-effort) |

**Downlink topics** in the per-device tree that the firmware **never** publishes
or subscribes to (operator → mirror; documented here for completeness, root
`CLAUDE.md §9.1`):

| Topic | Publisher | Subscriber | Payload |
|---|---|---|---|
| `rmms/<uuid>/info` | operator cert (PoC laptop; prod Radxa relay) | mirror | `{"text":"...","wall_ms":…}` |
| `rmms/<uuid>/screen` | operator cert | mirror | `{"page":1..4,"wall_ms":…}` |

> There is **no IR camera** (dropped, root `CLAUDE.md §17`) and **no
> `rmms/ui/...` namespace** (retired — the mirror reads the raw topics directly,
> root `CLAUDE.md §9.5`). If you find either referenced anywhere, it's stale.

---

## Payload envelope (all sensor topics)

Every sensor sample uses the same outer wrapper (root `CLAUDE.md §9.2.1`):

```json
{
  "ts_us":   1234567890,
  "wall_ms": 1716210000000,
  "seq":     42,
  "q":       0,
  "v":       { }
}
```

| Field | Type | Meaning |
|---|---|---|
| `ts_us` | uint64 | Monotonic microseconds since boot. Always present, always valid. |
| `wall_ms` | int64 | Wall-clock ms since the Unix epoch. **`-1` sentinel** until the first `time/set`. **Never omitted** — use the sentinel, do not drop the field. |
| `seq` | uint32 | Per-topic monotonic counter, persisted across reboots (monotonic-with-gaps). Used by the SBC for dedup. |
| `q` | uint8 | Quality flag (below). |
| `v` | object | Sensor-specific body — see per-sensor sections. |

Quality flag (`q`):

| `q` | Meaning | Consumer action |
|---|---|---|
| 0 | OK — fresh, plausible | Use normally |
| 1 | Stale — cached value returned | Use with caution |
| 2 | Degraded / validating — ghost reading, warm-up, or carried on older window data | Use with caution; FHIR `preliminary` |
| 3 | Invalid — hardware error or driver not ready | Discard; do not display or forward to FHIR |

The firmware never silently drops a sample; it sets `q` instead (root
`CLAUDE.md §9.2.1`, audit anti-pattern §19.1).

---

## `rmms/<uuid>/env` — environment sample

Inner `v` object:

```json
{"temp_c": 21.500, "hum_pct": 55.000, "pres_hpa": 1013.250}
```

- `temp_c` — temperature in °C (`%.3f`).
- `hum_pct` — relative humidity 0–100 % (`%.3f`), **or `null`** when the BMP280
  driver is active (it has no humidity sensor).
- `pres_hpa` — atmospheric pressure in hPa (`%.3f`), **or `null`** when the
  AHT21 driver is active (it has no pressure sensor).
- Exactly one of `hum_pct` / `pres_hpa` is `null`, depending on which env part
  is populated. Receivers must not assume either is numeric (root
  `CLAUDE.md §9.2.2`/§9.2.3).

---

## `rmms/<uuid>/air` — air-quality sample (ENS160)

Inner `v` object:

```json
{"co2_ppm": 600, "tvoc_ppb": 300, "aqi": 2}
```

- `co2_ppm` — equivalent CO₂ estimate, integer ppm.
- `tvoc_ppb` — total VOC estimate, integer ppb.
- `aqi` — UBA air-quality index, integer 1–5 (1 excellent … 5 unhealthy).

The ENS160 needs an undocumented warm-up (~5–10 min) after power-up; samples
during that window carry `q=2`. The env driver's last temp/hum is written to the
ENS160 TEMP_IN/RH_IN compensation registers every cycle.

---

## `rmms/<uuid>/radar` — radar sample

Produced by either radar driver — the Seeed MR60BHA2 (60 GHz, `"radar":"bha2"`)
or the Waveshare HMMD module (24 GHz, `"radar":"hmmd"`, ADR-0007) — via the
common `radar_driver_t` interface, so the inner object is radar-independent (root
`CLAUDE.md §3.2`/§7.4). Fields a given radar does not report are sent as the
documented sentinel / `null`. The HMMD is a **presence + distance** radar with
no respiration or heart sensing, so on an HMMD module `breath_bpm`, `heart_bpm`,
and `resp_motion` are **always `null`** while `presence` and `distance_mm` are
live — legitimately absent data, not a fault.

Inner `v` object:

```json
{"presence": true, "distance_mm": 2400, "breath_bpm": 16.5, "heart_bpm": 72.0, "resp_motion": true}
```

- `presence` — bool, always present.
- `distance_mm` — distance to closest target in mm; `null`/`0` if not reported.
- `breath_bpm` — breathing rate; `null` if not reported this cycle **or
  suppressed during a breath-hold**.
- `heart_bpm` — heart rate; `null` if not reported this cycle.
- `resp_motion` — ADR-0006 phase-based breath-hold detection: `true` = chest
  motion present, `false` = no respiratory motion (possible hold; `breath_bpm`
  is nulled for that sample), `null` = undetermined (no presence/distance lock or
  no valid breath-phase amplitude). Always present. A suspected indicator, not a
  clinical apnea alarm; FHIR mapping TBD (root `CLAUDE.md §9.6`).

Quality notes: `q=2` when presence is asserted but vitals are implausible
(ghost-detection) or values are carried on older window data; `q=3` on UART
error / driver not ready. (The plausibility/median filtering is
[ADR-0005](adr/0005-mcu-side-radar-filtering.md).)

---

## `rmms/<uuid>/light` — light sample

Inner `v` object:

```json
{"lux": 120.5}
```

Same payload for both light variants (root `CLAUDE.md §3.2`, ADR-0001): BH1750
(I²C, calibrated lux directly — the default) or GL5516 LDR (ADC0 + 1 kΩ divider,
per-board power-law calibration).

---

## `rmms/<uuid>/status` — device status (retained)

Plain UTF-8 string (not a JSON object). Two values only:

| Value | When |
|---|---|
| `"online"` | published retained on each MQTT CONNACK |
| `"offline"` | the broker publishes this LWT if the connection drops |

Retained, so a late subscriber immediately sees the current state.

---

## `rmms/<uuid>/cmd` — command (subscribed)

The firmware subscribes and processes this **closed** set. Payloads are JSON
objects with a `"cmd"` key (parsed by the jsmn tokenizer, root `CLAUDE.md §9.2`):

| Command | Payload | Action |
|---|---|---|
| `activate` | `{"cmd":"activate"}` | Start publishing sensor data |
| `deactivate` | `{"cmd":"deactivate"}` | Stop publishing, keep the connection |
| `deregister` | `{"cmd":"deregister"}` | Clear all `/cfg/` config (not certs); factory reset to unconfigured |
| `shutdown` | `{"cmd":"shutdown"}` | Drop links and idle; recover on power cycle |

Adding commands requires the Radxa team's sign-off first (root `CLAUDE.md §9.3`).
`deregister_sbc` from the previous group is removed and must not return.

---

## `rmms/<uuid>/time/set` — wall-clock sync (subscribed)

```json
{"epoch_ms": 1716210000000}
```

Published per-device by the broker LAN's time-sync publisher (the SBC aggregator
in the live stack) when a device connects. The firmware maintains a wall-clock
offset and stamps each spooled record's `wall_ms` (§9.2.5, ADR-0003). No
NTP-from-WAN.

---

## `rmms/<uuid>/log` — log line

Plain UTF-8 text (not a JSON object). Best-effort QoS 0, not retained. One line
per publish, only for critical errors (`LOG_E`).

---

## Namespace rules

- The firmware publishes **only** the topics listed as `publish` above
  (`env`, `air`, `radar`, `light`, `status`, `log`). It publishes raw numeric
  vitals — that *is* the contract; the mirror does its own thresholding in
  `MMM-SensorUI.js` (root `CLAUDE.md §9.5`).
- The firmware subscribes **only** to `rmms/<uuid>/cmd` and
  `rmms/<uuid>/time/set`.
- The firmware **never** publishes or subscribes to `info` / `screen` (operator →
  mirror downlink) and there is **no `rmms/ui/...` namespace**.
- No spaces, no Dutch diacritics, no PII in topic strings.

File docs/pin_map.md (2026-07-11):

# Pin Map

Human-readable mirror of `components/board/board_pico2wh.h` (updated to the v1
PoC wiring, 2026-06-03). **`board_pico2wh.h` is authoritative**; this file is the
human reference. Do not hardcode GPIO numbers in firmware — always use the
`BOARD_*` constants. Pin assignments are PCB-owned; changing the header needs an
ADR (root `CLAUDE.md §19`).

---

## I²C0 — environment + air + light + OLED

All I²C peripherals share one bus (one mutex, root `CLAUDE.md §7.2`).

| GPIO | Pin | Signal | `BOARD_*` | Notes |
|---|---|---|---|---|
| 8 | 11 | I2C0_SDA | `BOARD_I2C_SDA_PIN` | pull-up to 3V3 on PCB |
| 9 | 12 | I2C0_SCL | `BOARD_I2C_SCL_PIN` | pull-up to 3V3 on PCB |

- Bus instance `i2c0` (`BOARD_I2C_INST`); frequency 400 kHz
  (`BOARD_I2C_FREQ_HZ`, override `-DBOARD_I2C_FREQ_HZ=100000U` for a slow-mode
  diagnostic build that tolerates marginal pull-ups).
- Device addresses:

  | Device | Addr | `BOARD_*` | Notes |
  |---|---|---|---|
  | BMP280 (env, default-populate) | `0x76` | `BOARD_BMP280_ADDR` | `0x77` if SDO high; chip ID `0x58` (it is a BMP280, not a BME280 — no humidity) |
  | AHT21 (env, alt-populate) | `0x38` | `BOARD_AHT21_ADDR` | fixed address |
  | ENS160 (air quality) | `0x53` | `BOARD_ENS160_ADDR` | `0x52` if ADDR pulled low |
  | BH1750 (light, advanced module) | `0x23` | `BOARD_BH1750_ADDR` | `0x5C` if ADDR pulled high |
  | SH1122 OLED (256×64) | `0x3C` | `BOARD_OLED_ADDR` | `0x3D` if SA0 high |

  The env footprint takes BMP280 **or** AHT21; the light footprint takes BH1750
  (here) **or** the GL5516 LDR (ADC, below). Selection is via `/cfg/sensors.json`
  (root `CLAUDE.md §3.2`, ADR-0001).

---

## UART1 — mmWave radar

| GPIO | Pin | Direction | Signal | `BOARD_*` | Notes |
|---|---|---|---|---|---|
| 5 | 7 | Output | UART1_TX | `BOARD_RADAR_TX_PIN` | MCU TX → radar RX |
| 4 | 6 | Input | UART1_RX | `BOARD_RADAR_RX_PIN` | MCU RX ← radar TX |

- Instance `uart1` (`BOARD_RADAR_UART_INST`); 115200 baud (`BOARD_RADAR_BAUD`).
- The `radar_driver_t` v-table carries the **Seeed MR60BHA2** (advanced module,
  `"radar":"bha2"`) and the **24 GHz HMMD** module (generic module,
  `"radar":"hmmd"`, [ADR-0007](adr/0007-hmmd-radar-second-driver.md)); a
  **DFRobot C1001** driver is in development (a third driver behind the same
  seam). Selected at runtime via `/cfg/sensors.json` `"radar"` (root
  `CLAUDE.md §7.4`) — no rebuild to swap.
- Radar runs from its own 5 V rail (high RF draw — never power from MCU 3V3).

### Radar discrete GPIO indicators (in addition to UART data)

The UART carries the full payload; these discrete lines are useful for fast
presence-edge detection and bring-up sanity checks.

| GPIO | Pin | `BOARD_*` | Notes |
|---|---|---|---|
| 2 | 4 | `BOARD_MR60BHA2_PRESENCE_PIN` | HMMD presence line |
| 3 | 5 | `BOARD_MR60BHA2_LED_PIN` | onboard RGB-LED indicator |
| 6 | 9 | `BOARD_C1001_PRESENCE_PIN` | DFRobot C1001 (driver in development) — see note |
| 7 | 10 | `BOARD_C1001_FALL_PIN` | DFRobot C1001 fall-detection (driver in development) — see note |

> **C1001 note:** a DFRobot C1001 (24 GHz) driver is **in development** as a
> third radar behind the `radar_driver_t` v-table (alongside the MR60BHA2 and the
> HMMD module, ADR-0007). The header wires its presence/fall lines on the generic
> module footprint; as with the MR60BHA2's discrete lines, the UART carries the
> full payload — these GPIOs are for fast presence-edge detection / bring-up
> sanity. Until the driver lands and a `"radar":"c1001"` branch exists in
> `radar_select.c` (today it knows `"bha2"` and `"hmmd"`), selecting it is a no-op.

---

## ADC0 — GL5516 LDR (generic-module light variant)

Populated only on the generic module; the advanced module leaves this unpopulated
and uses the BH1750 over I²C instead.

| GPIO | Pin | Signal | `BOARD_*` | Notes |
|---|---|---|---|---|
| 26 | 31 | ADC0 | `BOARD_LDR_ADC_GPIO` | ADC input index 0 (`BOARD_LDR_ADC_INPUT`) |

- Divider: `3V3 ── LDR (GL5516) ── ADC_NODE ── 1 kΩ ── GND`, so
  `V = VCC × R_fixed / (R_LDR + R_fixed)`. Constants: `BOARD_LDR_VCC_V = 3.3`,
  `BOARD_LDR_FIXED_OHM = 1000.0` (ADR-0001).
- GP26 must not be used for digital I/O while the ADC is active.

---

## GPIO — button

v1 PoC has **one** user button (display-cycle); reset is the on-board RUN pin.

| GPIO | Pin | Signal | `BOARD_*` | Notes |
|---|---|---|---|---|
| 16 | 21 | BTN_DISPLAY | `BOARD_BTN_DISPLAY_PIN` | active-low, internal pull-up; advances the OLED page |

Software debounce: 50 ms one-shot FreeRTOS timer (`ui_input.c`).

---

## GPIO — LEDs

| GPIO | Pin | Signal | `BOARD_*` | Notes |
|---|---|---|---|---|
| 15 | 20 | LED_POWER | `BOARD_LED_POWER_PIN` | "system on" indicator (swapped to match as-built PCB) |
| 14 | 19 | LED_WIFI | `BOARD_LED_WIFI_PIN` | "wifi associated" indicator (swapped to match as-built PCB) |
| — | — | CYW43 onboard LED | (via `pico_cyw43_arch`) | net-state; not a bare GPIO |

---

## Generic / reserved GPIO breakouts

Exposed on the PCB, not bound to a sensor in v1 (traceability against the
schematic): `BOARD_GPIO_D0` = GP1 (pin 2), `BOARD_GPIO_D2` = GP13 (pin 17),
`BOARD_GPIO_D8` = GP10 (pin 14), `BOARD_GPIO_D9` = GP11 (pin 15),
`BOARD_GPIO_D10` = GP12 (pin 16).

---

## USB

TinyUSB owns the USB peripheral; no GPIO constants are needed (D+/D− are fixed in
silicon). In v1, USB enumerates a **single USB-serial dev console**
(`pico_stdio_usb`, root `CLAUDE.md §12`) for developer logs — it is **not** a
tablet data link.

> The header's comment still reads "CDC0 = data, CDC1 = logs" — that describes
> the **removed** dual-CDC USB-CDC transport ([ADR-0002](adr/0002-wifi-sole-transport.md)).
> v1 has no USB data path; only the single dev console. (The header is PCB-owned;
> correcting that comment is an ADR-gated change, so it is annotated here instead.)

---

## Power

| Rail | Source | Consumers |
|---|---|---|
| 5 V mains | External PSU | MCU (V-SYS pin 39), mmWave radar (isolated rail) |
| 3V3 (from MCU) | Pico 2 WH onboard LDO (OUT pin 36) | BMP280/AHT21, ENS160, BH1750, OLED, LDR, button, LEDs |
| Radar 5 V | Separate mains rail | Seeed MR60BHA2 (high RF draw) |

Common ground on pin 38. The radar must not share its 5 V supply with the MCU
rail — keep them isolated to avoid RF noise coupling (root `CLAUDE.md §3.3`).

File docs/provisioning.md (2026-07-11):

# Provisioning — CA, certificates, and device identity

How a fresh workstation goes from nothing to a fully provisioned fleet:
project CA → broker/mirror/operator bundles → per-device bundles → files on
the Pico's littlefs. This is the operational companion to `CLAUDE.md §9.4`
(identity model) and `§10.2` (crypto constraints). There is **no enrollment
protocol** — devices are born with their identity at provisioning time.

Everything below is driven by two scripts; their header comments are the
authoritative usage docs:

- `scripts/provision_ca.sh` — mints the CA (once) and all certificate bundles.
- `scripts/provision_device.py` — pushes a device bundle onto a Pico over
  USB-serial (pairs with the `bringup_provision.uf2` image).

`scripts/deploy_home_kit.sh` orchestrates the whole home-kit (broker + mirror
+ device bundles + tablet deploy) on top of these; for a single device the
manual flow below is enough.

## 1. One-time: create the CA and the infrastructure identities

```bash
BROKER_IP=<tablet-LAN-ip> ./scripts/provision_ca.sh
```

First run creates, all ECDSA P-256:

| Output | Purpose |
|---|---|
| `~/rmms-ca/` (mode 700, gitignored) | **CA private key — never leaves this directory.** |
| `out/broker/` (`ca.crt`, `broker.crt`, `broker.key`, `mosquitto.conf`, `acl`) | Mosquitto mTLS listener on the tablet. |
| `out/mirror-<id>/` (PEM) | MagicMirror²'s `MMM-CustomMQTTBridge` subscriber identity (`CN=mirror-<id>`; generated ACL: `topic read rmms/#`, read-only over the whole device tree). |
| `out/operator-<id>/` (PEM) | Operator identity for publishing `info`/`screen` (`CN=operator-<id>`). |
| `out/device-<uuid>/` (DER + PEM) | First device bundle. |

`BROKER_HOST` (default `tablet.local`) and `BROKER_IP` go into the broker
cert's SAN — set `BROKER_IP` to the tablet's real LAN IP or TLS hostname
verification will fail for IP-based connects. Cert lifetimes: CA 10 years
(`CA_DAYS`), leaves 2 years (`LEAF_DAYS`, per `CLAUDE.md §16 Q8`).

## 2. Per device: mint a bundle, add the config files, push it

```bash
# Mint the certs (reuses the existing CA/broker/mirror/operator):
./scripts/provision_ca.sh                       # or DEVICE_UUID=... to re-issue
```

**`provision_ca.sh` produces only the certs + `device.json`.** The three
config files the firmware also needs must be added to `out/device-<uuid>/`
by hand (schemas: `CLAUDE.md §11`; `provision_device.py` silently skips any
that are missing, and a device without them can never connect):

```bash
cd out/device-<uuid>
cat > wifi.json    <<'J'
{"_v":1,"ssid":"<your-ssid>","psk":"<your-psk>","country":"NL"}
J
cat > broker.json  <<'J'
{"_v":1,"host":"tablet.local","ip":"","port":8883}
J
cat > sensors.json <<'J'
{"_v":1,"radar":"bha2","env":"aht21","light":"bh1750"}
J
```

`sensors.json` selects the populated hardware variant
(`radar: "bha2"|"hmmd"`, `env: "bmp280"|"aht21"`, `light: "bh1750"|"gl5516"`).
(`scripts/deploy_home_kit.sh` automates broker.json + a default sensors.json
for new device dirs, but wifi.json is always yours to write — credentials
never live in the repo.)

```bash
# Flash the provisioning firmware, then push the bundle over USB-serial:
cp build/test/bringup/bringup_provision.uf2 /run/media/$USER/RP2350/
./scripts/provision_device.py /dev/ttyACM0 out/device-<uuid>
```

`provision_device.py` writes each file to the canonical littlefs paths
(`/certs/ca.der`, `/certs/dev.crt`, `/certs/dev.key`, `/cfg/*.json` — see
`CLAUDE.md §11`), verifies device-reported SHA-256 per file, runs a final
integrity check, and reboots. After that, flash the real firmware
(`sensor_module.uf2` or `bringup_sensors.uf2`) — reflashing firmware never
touches `/certs` or `/cfg`.

## 3. Verifying the chain end-to-end

- `scripts/test_broker_acl.sh <broker-ip>` proves the Mosquitto ACL: device
  writes only its own subtree, mirror reads everything, operator writes only
  `info`/`screen`, no-cert connections refused (7/7 assertions — bring-up
  step 12, `CLAUDE.md §16 Q9`).
- `docs/report/mqtt_mtls_proof/` holds captured evidence of the mTLS
  handshake, no-cert refusal, and publish/PUBACK against the live tablet
  broker (PEM bodies redacted per `§19`).

## 4. CA custody (§16 Q7 — read before the handover ends)

The security of the entire fleet is the security of `~/rmms-ca/` on the
provisioning workstation. Rules, from `CLAUDE.md §10.2`:

- The CA key never touches a deployed device, the repo, or a shared drive.
- Whoever inherits the project must either **(a) receive `~/rmms-ca/` via an
  encrypted, offline transfer** (encrypted USB stick, then delete the source
  copy), or **(b) regenerate the CA** — which means re-provisioning *every*
  identity: broker, mirror, operator, and each device (re-flash
  `bringup_provision.uf2` + re-push bundles). Option (b) is a clean start and
  takes under an hour for a handful of devices; prefer it if there is any
  doubt about the old key's exposure.
- If a single **device** cert is compromised: re-issue with
  `DEVICE_UUID=<uuid> ./scripts/provision_ca.sh` and re-provision that device.
  (No revocation infrastructure exists in v1 — the broker trusts the CA, so a
  stolen device key is only fully neutralized by rotating the CA. Known v1
  limitation, `CLAUDE.md §10.4`.)
- Compromise of the provisioning workstation = compromise of the fleet.
  Rotate the CA (option b).

## 5. What is deliberately absent

No bootstrap credentials, no shared enrollment secret, no QR codes, no UDP
broker discovery, no on-device key generation, no OTA cert rotation. These
were all failure modes of the previous group's design (`docs/technical-audit.md`
§D) and are excluded by `CLAUDE.md §9.4`/`§10`. Re-introducing any of them
requires an ADR that defeats the audit's findings.

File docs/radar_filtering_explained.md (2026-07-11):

HOW THE RADAR FILTERING WORKS (in simple terms)
================================================

All of this lives in one file: components/sensor_radar/radar_filter.c
The design write-up is at the top of radar_filter.h, and the rationale is in
docs/adr/0005-mcu-side-radar-filtering.md.

WHY THE FILTER EXISTS
---------------------
The raw 60 GHz radar (MR60BHA2) is jumpy. Left alone, the numbers flicker every
frame, "ghost" targets make presence blink on and off, distance jitters, and
heart/breath rates bounce around. If we sent that straight to the mirror, the
tiles would be unreadable. So before any radar sample goes on the wire, it
passes through a plausibility filter that DEBOUNCES, VALIDATES, and SMOOTHS it.

Key point: the filter is pure logic. It takes one raw sample in and gives one
cleaned sample out - same shape, same fields. It doesn't touch hardware, so it
works for any radar (including the HMMD), and we can unit-test it on a laptop.

The whole thing is one function, radar_filter_apply(), called once per radar
reading. Think of it as a pipeline of stages:

STAGE 1 - IS SOMEONE ACTUALLY THERE? (presence debounce)
--------------------------------------------------------
We don't trust a single "presence" blip. Presence "evidence" = the radar's
presence flag OR a distance reading that falls in a sensible range.

  - Evidence has to persist for 10 seconds before we declare "present."
  - Once present, we need 8 seconds of silence before we declare "absent."

This is the classic anti-flicker trick: a brief ghost can't flip presence on,
and a momentary dropout can't flip it off.

STAGE 2 - IS THE DISTANCE BELIEVABLE? (gate + smooth)
-----------------------------------------------------
A distance reading is processed by a reusable little component called
StableValueFilter. It does four things in order:

  1. Range gate  - throw away anything outside 0.35 m - 1.5 m. Physically
     impossible readings are silently ignored.
  2. Jump guard  - if the value suddenly leaps more than 20 cm, treat it as a
     new candidate and restart the clock (don't believe a teleport).
  3. Confirm window - the value has to stay stable for ~6 s before we trust it.
  4. Low-pass smoothing - once trusted, a time-aware average glides toward new
     readings instead of snapping, so the displayed distance is smooth.

STAGE 3 - HEART AND BREATH RATES
--------------------------------
Vitals are only looked at when presence AND distance are both locked in.
Otherwise we'd be reading vitals off noise. Each vital then goes down two
parallel paths:

  A) The LIVE path (what the mirror actually shows).
     Each vital keeps a rolling 30-second list of recent readings and publishes
     the MEDIAN of that list. The median is the magic here: a single garbage
     reading gets out-voted by the good ones instead of throwing the display
     off. There's a two-tier twist - it prefers the last ~12 s of readings so
     the tile reacts when your real breathing rate changes, but if the sensor
     goes quiet (it sends heart and breath in alternating bursts), it falls back
     to the full 30 s so the number doesn't blank out. A value shows after ~5
     readings accumulate, and disappears if it goes too stale (>25 s old) or the
     person leaves.

  B) The ESTIMATE path (see Stage 5).

There's also a calibration step: the sensor reads high, so we subtract a fixed
offset (20 BPM off heart, 2 RPM off breath) at output time - a bench-measured
correction.

STAGE 3b - BREATH-HOLD DETECTION
--------------------------------
The breath RATE is a windowed frequency, so it can't drop during a held breath.
But the raw chest-motion AMPLITUDE does go flat. So we watch the amplitude: if
it stays below a threshold for ~5 s, we report "no respiratory motion" (a
possible breath-hold), null out the breath rate, and the mirror shows "No
breathing." One real breath clears it. (Hysteresis + a confirm window stop it
from triggering on the quiet pause at the top of a normal breath.)

STAGE 4 - THE QUALITY FLAG (q)
------------------------------
Every published sample gets a quality marker so the downstream Radxa knows how
much to trust it:
  0 = fresh and good
  2 = still validating or the value is a bit stale (preliminary)
  3 = invalid, with nothing to show
We never silently drop a sample - we always label it.

STAGE 5 - THE ROBUST "BEST ESTIMATE" (logged, not displayed)
------------------------------------------------------------
Separately, while a vital is stable we collect one clean sample per second into
a 20-second window, then reduce it to a single robust number using median + MAD
outlier rejection (statistically throw out the weird ones, average the rest).
It's logged to the dev console, not put on the wire. It's a higher-confidence
"this is really their heart rate" number for debugging/validation.

THE ONE-SENTENCE VERSION
------------------------
Raw radar is noisy, so before publishing we (1) require steady evidence before
saying someone's present, (2) reject impossible distances and smooth the rest,
(3) show the median of recent heart/breath readings so a single bad value can't
throw the tile off, (4) detect breath-holds from chest-motion amplitude, and
(5) tag every sample with a quality flag instead of ever dropping one.

The tunable constants (ranges, timeouts, thresholds) are all #defines at the top
of radar_filter.h with comments explaining where each number came from - most
were tuned against a live sensor on the bench.

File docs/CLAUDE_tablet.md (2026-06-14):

# CLAUDE.md — RMMS Tablet tier

> Read this file completely before working on the tablet-side stack.
> The firmware's `CLAUDE.md` (repo root) is the single source of truth for the
> whole system; **if anything here contradicts it, the root file wins.** This
> file documents the tablet tier specifically: the MQTT broker, MagicMirror²,
> mDNS, the presence→screen bridge, and Android autostart glue.
>
> **Scope note:** the tablet artifacts currently live **in this monorepo**
> (`scripts/tablet_*.sh`, `MagicMirror/`, `out/broker/`) as a temporary
> convenience; factor them into a separate tablet repo before v1 (root
> `CLAUDE.md §1`). The firmware build never compiles any of this.

---

## 1. Project context

The Android tablet sits behind the two-way acrylic mirror and plays **two
roles simultaneously**:

1. **MQTT broker** — Mosquitto under Termux, mTLS on `:8883`. The central
   message bus for the sensor module(s), the SBC aggregator, the mirror, and
   the operator.
2. **MagicMirror² client** — the smart-mirror UI for the resident. It
   subscribes **directly to the firmware's raw `rmms/<uuid>/...` topics on its
   own broker** and renders per-sensor tiles.

The tablet is the hub of a three-tier system:

```
Sensor Module ──► Tablet ───────────────► Radxa / SBC ──► Hospital FHIR
  (firmware       (broker + mirror)        (sbc/)          (external)
   repo root)     (THIS tier)
```

The previous BAP group put the broker on their SBC; the tablet-as-broker model
fixes several reliability issues at the cost of Android lifecycle complexity
(Doze, Termux quirks). This tier manages that complexity.

> **What changed vs. earlier drafts of this file (now corrected):**
> - **There is no USB-MQTT bridge.** USB-CDC was dropped from v1 and the whole
>   `socat` byte-pipe / `bridge/` idea is gone — Wi-Fi is the sole transport
>   ([ADR-0002](adr/0002-wifi-sole-transport.md)). The firmware reaches the
>   broker over Wi-Fi mTLS only.
> - **The wire format is JSON** (RFC 8259, root `CLAUDE.md §9.2`), not CBOR.
> - **There is no `rmms/ui/...` namespace and no `MMM-RMMS` module.** The mirror
>   consumes the **raw** topics via `MMM-CustomMQTTBridge` → `MMM-SensorUI`
>   (root `CLAUDE.md §9.5`).
> - **The mirror shows numbers.** Per-tile numeric value + severity colour is
>   the design (root `CLAUDE.md §9.5`); the old "no raw numbers" rule is wrong.

---

## 2. Components

The tablet runs these, roughly in dependency order:

| Component | What it is | Where it lives |
|---|---|---|
| Mosquitto | MQTT broker, mTLS `:8883` (+ loopback `:1883` for app IPC) | config: `out/broker/{mosquitto.conf,acl}` → tablet `~/rmms/` |
| MagicMirror² | Smart-mirror UI (`npm run server`, Chrome viewer) | `MagicMirror/` (custom modules under `MagicMirror/modules/`) |
| mDNS responder | Advertises `tablet.local` so devices find the broker by name | `scripts/tablet_mdns_responder.py` |
| Presence→screen bridge | Wakes/sleeps the display from radar presence | `scripts/tablet_presence_screen.py` |
| Termux:Boot autostart | Brings everything up at device boot | `scripts/tablet_boot.sh` → `~/.termux/boot/10-rmms` |

`scripts/tablet_start_magicmirror.sh` launches and supervises MagicMirror².
There is **no bridge process** — that line item from earlier drafts is deleted.

---

## 3. Mosquitto broker

### 3.1 Why Mosquitto

It is in Termux's package repo (`pkg install mosquitto`) and is the same broker
used on the dev workstation and in CI. One implementation, one config syntax.
Do not substitute mosca, NanoMQ, or EMQX.

### 3.2 Configuration (live: `out/broker/mosquitto.conf`)

Two listeners, generated by `scripts/provision_ca.sh` and deployed to the
tablet's `~/rmms/`:

```
per_listener_settings true

# ── Network listener — the firmware's broker contract ───────────────────────
# Mutual TLS, cert CN as username, ACL-enforced. The ONLY network-facing
# listener. Firmware, mirror, operator, SBC, and the presence bridge's READ side.
listener 8883 0.0.0.0
protocol mqtt
allow_anonymous false
require_certificate true
use_identity_as_username true
cafile   /data/data/com.termux/files/home/rmms/certs/ca.crt
certfile /data/data/com.termux/files/home/rmms/certs/broker.crt
keyfile  /data/data/com.termux/files/home/rmms/certs/broker.key
acl_file /data/data/com.termux/files/home/rmms/acl

# ── Localhost-only plain listener — on-device app IPC ONLY (ADR-0004) ────────
# Bound to 127.0.0.1, so NOT network-reachable: no firmware traffic touches it.
# Carries the HealthMonitorWakeTest `display` topic + the presence bridge's
# WRITE side (see presence_screen_coupling.md). A *network*-facing plain
# listener would violate the mTLS contract; this loopback one does not.
listener 1883 127.0.0.1
protocol mqtt
allow_anonymous true

persistence false
log_dest stdout
```

Notes:
- Certs are PEM (`ca.crt` / `broker.crt` / `broker.key`), not DER. (The Pico's
  own copies are DER — that is a device-side detail, see root `CLAUDE.md §10.2`.)
- `tls_version` is left at the Mosquitto default (TLS 1.2+); the device pins the
  cipher suites (root `CLAUDE.md §10.2`).
- The `:1883` loopback listener is the **only** plaintext path in the system and
  is unreachable from the network ([ADR-0004](adr/0004-localhost-plain-listener-app-ipc.md)).

### 3.3 ACL (live: `out/broker/acl`)

Pattern-based and CN-keyed — **adding a device needs zero broker config**.
`use_identity_as_username true` makes `%u` resolve to the client cert's CN.

```
# ─── Per-device pattern (CN = UUID) ─────────────────────────────────────────
pattern write rmms/%u/#
pattern read  rmms/%u/cmd

# ─── Mirror role (read-only across the whole device tree) ───────────────────
user mirror-<id>
topic read rmms/#

# ─── Operator role (downlink info/screen only) ─────────────────────────────
user operator-<id>
topic write rmms/+/info
topic write rmms/+/screen

# ─── SBC / Radxa role (appended by deploy_home_kit.sh) ──────────────────────
#   reads raw vitals, publishes per-device time-sync
user radxa-<home>
topic read  rmms/+/env
topic read  rmms/+/air
topic read  rmms/+/radar
topic read  rmms/+/light
topic read  rmms/+/status
topic write rmms/+/time/set
```

The base file (device pattern + mirror + operator) is written by
`provision_ca.sh`; the `radxa-<home>` block is appended idempotently by
`deploy_home_kit.sh`. `scripts/test_broker_acl.sh <broker-ip>` proves the
enforcement (7/7: own-subtree write OK, cross-device write denied, operator
info/screen OK, operator env denied, device cmd read OK, cross-read denied,
anonymous refused).

### 3.4 Persistence

The live config sets `persistence false` — the broker is a relay, and
loss-tolerance is owned end-to-end by the device's flash spool (ADR-0003) plus
the SBC's ≥24 h SQLite queue. If you ever enable persistence, keep the file in
Termux app-private storage (`~/...`), **never** on `/sdcard` (scoped storage,
unsafe fsync).

---

## 4. MagicMirror²

### 4.1 Run mode (resolved — root `CLAUDE.md §16 Q4`)

Termux + Node.js running `npm run server` (server-only, no Electron) on `:8080`;
Chrome on the tablet opens `http://localhost:8080`. `scripts/tablet_start_magicmirror.sh`
launches it and restarts on death with backoff. A production kiosk lock (Fully
Kiosk Browser) is optional and not needed for the v1 PoC.

### 4.2 The two custom modules

The mirror consumes the firmware's **raw** topics. Two modules
(`MagicMirror/modules/`):

- **`MMM-CustomMQTTBridge`** — does mTLS to the broker with the **mirror cert**,
  subscribes to `rmms/+/+`, parses the §9.2 JSON envelope, and re-broadcasts
  each logical field as an in-process `sensors/<field>` notification. This is
  the single translation point between the wire namespace (`rmms/<uuid>/...`)
  and the mirror-internal namespace (`sensors/...`) — see root `CLAUDE.md §9.5.1`.
  The canonical mapping table lives at the top of its `node_helper.js`.
- **`MMM-SensorUI`** — renders the tiles and owns **all** threshold→severity
  logic (`green`/`yellow`/`orange`/`red`, cited to WHO/AHA/ASHRAE). It shows the
  numeric value **and** the severity check per tile, handles the breath-hold
  tile (`resp_motion:false` → "No breathing", ADR-0006), hyperventilation, and
  "Measuring…" placeholders. It only consumes `sensors/...`; it never parses
  JSON or sees `q`/`wall_ms`/`seq`.

`MMM-pages` rotates between the sensor UI and other pages (e.g. video conf).

`MMM-MQTT` is **not** used. If you see a reference to it, it's stale.

### 4.3 Module config (live: `MagicMirror/config/config.js`)

`config.js` registers `clock`, `MMM-SensorUI`, `MMM-VidConf`, and
`MMM-CustomMQTTBridge`. The bridge block carries the broker URL, the mirror
`clientId` (= mirror cert CN), absolute paths to the mirror bundle
(`out/mirror-<id>/{ca.crt,cert.pem,key.pem}`), and `topics: ["rmms/+/+"]`:

```javascript
{
  module: "MMM-CustomMQTTBridge",
  config: {
    broker:   "mqtts://<broker-ip-or-tablet.local>:8883",
    clientId: "mirror-<id>",                 // must equal the mirror cert CN
    caFile:   process.env.HOME + "/.../out/mirror-<id>/ca.crt",
    certFile: process.env.HOME + "/.../out/mirror-<id>/cert.pem",
    keyFile:  process.env.HOME + "/.../out/mirror-<id>/key.pem",
    topics:   ["rmms/+/+"]
  }
}
```

> `config.js` is **untracked** (it holds the LAN-specific broker IP — commit
> 985c189). `deploy_home_kit.sh` renders it per-home. Leaving the three file
> paths empty + `broker: "mqtt://localhost:1883"` falls back to the plaintext
> loopback for a no-TLS bench rig.

### 4.4 Mirror cert

The mirror is a distinct MQTT identity with its own cert (CN `mirror-<id>`),
issued by the same project CA as the device certs (`provision_ca.sh`). ACL grant:
`topic read rmms/#`. The mirror never publishes sensor topics.

---

## 5. mDNS (`tablet.local`)

`scripts/tablet_mdns_responder.py` (python-zeroconf — avahi needs root/dbus and
is unreliable in Termux) advertises `tablet.local` → the tablet's current IP and
re-registers within ~5 s when DHCP moves it. Because the name is stable, each
device's `/cfg/broker.json` is provisioned **once** with
`{"host":"tablet.local","ip":""}` and never edited across networks (root
`CLAUDE.md §8.2`). Keep the tablet **awake** during a demo — Android suppresses
multicast RX with the screen off, which breaks resolution.

The previous group's UDP-broadcast discovery is dead and must not return. If a
LAN has no multicast, the fallback is to re-provision `broker.json` with a
literal IP.

---

## 6. Presence → screen coupling

`scripts/tablet_presence_screen.py` reads `rmms/<uuid>/radar` from the mTLS
`:8883` listener (mirror cert), debounces presence, and publishes ON/OFF to the
`display` topic on the loopback `:1883` listener, which the `HealthMonitorWakeTest`
Android app consumes to wake/lock the screen. Debounce defaults: 2 s on-delay,
10 s off-delay, 30 s keepalive, 15 s stale timeout
([presence_screen_coupling.md](presence_screen_coupling.md), ADR-0004). This
keeps presentation logic off the firmware — the device just publishes raw radar.

---

## 7. Autostart (self-healing)

Termux:Boot runs `scripts/tablet_boot.sh` (symlinked to `~/.termux/boot/10-rmms`)
on device startup. It is idempotent (`pgrep`-guarded) and brings up, in order:
acquire `termux-wake-lock` → wait for Wi-Fi → sshd → mosquitto → mDNS responder
→ presence bridge → MagicMirror². `runit`/the script restart services on death.

The tablet self-heals on reboot with no laptop and no fixed IP (mDNS). Two
**manual, un-scriptable** Android prerequisites (Android restrictions):

- **Disable battery optimization for Termux** — otherwise Doze kills everything
  within minutes even with the wake-lock.
- **Install Termux:Boot from F-Droid** (not Play Store) and **unlock the device
  once** after boot — Termux:Boot only fires after the first unlock.

Keep the tablet mains-powered and never let the display sleep (the mirror UI
*is* the screen).

---

## 8. Installation / deployment

Driven from the workstation by the tablet phase of
`scripts/deploy_home_kit.sh tablet <home-id> <tablet-ip>`, which: copies broker
certs + `mosquitto.conf` + `acl` to `~/rmms/`, copies the mirror bundle, installs
`tablet_boot.sh` as the Termux:Boot hook, renders `config.js`, optionally runs a
one-time Termux bootstrap (`pkg install` of openssh/mosquitto/python/nodejs +
`python-zeroconf`/`paho-mqtt`), and starts everything.

For a quick demo session, `scripts/demo_start.sh <tablet-ip>` re-mints the broker
cert for today's IP, (re)starts the mDNS responder + presence bridge, and relies
on the tablet's own Termux:Boot to keep mosquitto and MagicMirror up. SSH bootstrap
is one-time via `scripts/setup_tablet_ssh.sh <tablet-ip>`.

**Manual steps** (see §7): battery-opt off, Termux:Boot + add-ons from F-Droid,
unlock once after boot.

---

## 9. Open questions

1. **Tablet model / Android version.** Not finalized. Needs ≥4 GB RAM, Android
   10+, near-stock (avoid aggressive vendor process-killers).

**Resolved (do not reopen):**
- MagicMirror² run mode — Termux + `npm run server` + Chrome (§4.1, root §16 Q4).
- MMM bridge choice — `MMM-CustomMQTTBridge` (root §16 Q5).
- mDNS on Termux — python-zeroconf responder, `tablet.local` (§5, root §8.2).
- Time sync — a publisher on the broker LAN sends `rmms/<uuid>/time/set` when a
  device connects (ADR-0003; in the live stack this is the SBC aggregator,
  `sbc/src/rmms_aggregator/mqtt/publisher.py`); the tablet broker just relays it.
  The firmware stamps `wall_ms` from it (root §9.2.5).
- Transport — Wi-Fi only; **no USB-MQTT bridge** (ADR-0002).

---

## 10. Non-goals (v1)

- USB-MQTT bridge / any USB data path (removed — ADR-0002).
- A `rmms/ui/...` namespace or any firmware-republished UI topics (none exists).
- Web admin UI for the tablet stack (operate via SSH-into-Termux).
- OTA of the tablet software (reinstall).
- Tablet-side data analysis or FHIR (that is the SBC's job — `sbc/`).
- Voice / accessibility / multilingual UI.

---

## 11. References

- Root `CLAUDE.md` — especially §8.2 (Wi-Fi transport), §9.1/§9.2 (MQTT
  contract + JSON), §9.5 / §9.5.1 (mirror boundary + bridge mapping), §10
  (security model), §16 (resolved open questions).
- [ADR-0002](adr/0002-wifi-sole-transport.md) — Wi-Fi sole transport (USB-CDC
  and the byte-pipe bridge removed).
- [ADR-0004](adr/0004-localhost-plain-listener-app-ipc.md) — the loopback
  `:1883` app-IPC listener.
- [presence_screen_coupling.md](presence_screen_coupling.md) — debounce spec.
- `sbc/CLAUDE.md` — the aggregator + FHIR translator.
- Mosquitto config: <https://mosquitto.org/man/mosquitto-conf-5.html>.
- Termux:Boot: <https://github.com/termux/termux-boot>.
- MagicMirror²: <https://docs.magicmirror.builders/>.

---

## 12. Instructions for Claude Code specifically

- **Read this file and the root `CLAUDE.md` before changing the tablet tier.**
  Cite the section if a proposal conflicts.
- **There is no bridge to add MQTT/TLS logic to.** USB-CDC and the byte pipe are
  gone (ADR-0002). Do not reintroduce them without a new ADR.
- **The mirror reads raw `rmms/<uuid>/...` topics.** Threshold/severity logic
  lives in `MMM-SensorUI.js`; the wire→`sensors/*` mapping lives in
  `MMM-CustomMQTTBridge/node_helper.js`. There is no `rmms/ui/...` namespace.
- **The mirror shows numbers + severity per tile.** Do not strip numeric values.
- **No credentials, certs, or LAN IPs committed.** Certs live on the tablet /
  in `out/` (gitignored); `config.js` is untracked.
- **Mosquitto config is one file with two listeners** (`:8883` mTLS network,
  `:1883` loopback IPC). Do not add a network-facing plaintext listener.
- **Termux is not generic Linux.** Paths start with `/data/data/com.termux/...`;
  there is no systemd. Autostart is Termux:Boot + a wake-lock — if those aren't
  set up, no hack will keep services alive.

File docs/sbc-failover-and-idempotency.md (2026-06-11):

# SBC failover & end-to-end idempotency (cross-tier architecture)

This document specifies the **loss-tolerance and idempotency contract across all
three tiers** — sensor firmware → tablet broker → SBC gateway → hospital FHIR —
and shows where each requirement is satisfied. It is the "explicitly documented
system architecture" the requirements call for.

It is a **contract document**. Both tiers are implemented in this monorepo: the
firmware at the repo root (ADR-0003) and the SBC service under [`sbc/`](../sbc/),
a standalone Python project the firmware build never links. The SBC's
authoritative spec is [`sbc/CLAUDE.md`](../sbc/CLAUDE.md); this document
references it rather than restating it. Per CLAUDE.md §9.6, **there is no
FHIR/LOINC code on the MCU** — keeping the SBC in a separate project (not
compiled into the firmware) upholds that. The SBC owns all FHIR concerns.

> **Demo platform note.** Production target is the **Radxa Dragon Q6A**; the
> **Pine64 ROCKPro64** stands in for the demo. The SBC software is
> platform-portable (Ubuntu aarch64, Docker); the substitution changes nothing
> in this contract. (`sbc/CLAUDE.md` §1 records the original
> ROCKPro64→Q6A change; the demo simply runs the same service on the ROCKPro64.)

---

## 1. The three-tier topology

```
  Sensor firmware (this repo)        Tablet            SBC gateway (Radxa/ROCKPro64)     Hospital
  ───────────────────────────       ────────          ─────────────────────────────     ────────
  sensors → NV flash spool   ──mTLS──► Mosquitto ──mTLS──► MQTT subscriber                 FHIR R4
  (≥15 min, FIFO, QoS 1,             broker  :8883        → JSON → typed Sample            endpoint
   wall_ms-stamped)                                       → FHIR R4 Observation            (HAPI dev /
        ▲ retry until PUBACK                              → SQLite store-and-forward        real EHR)
        │                                                   (≥24 h outbound queue)   ──────►  ▲
        └── clears record only on PUBACK                  → POST Bundle (PUT/If-None-Exist)   │
                                                            idempotent on Observation.identifier
```

Two independent store-and-forward buffers, one per "hop that can fail":

| Buffer | Tier | Protects against | Capacity | Spec |
|---|---|---|---|---|
| **Flash spool** | Firmware | Wi-Fi / broker outage, device power loss | **≥15 min** (≈17 min) | ADR-0003 |
| **SQLite queue** | SBC | Hospital FHIR-endpoint / cloud outage | **≥24 h** outbound Observations | `sbc/CLAUDE.md` §10 |

---

## 2. Requirement-by-requirement traceability

### SBC = local gateway with cloud failover
When the hospital FHIR endpoint is unreachable, the SBC buffers locally and
replays on recovery — it does **not** drop. Implemented as the SQLite
`observations` table with `status ∈ {pending, posted, dead_letter}` and an
exponential-backoff retry/dead-letter path (`sbc/CLAUDE.md` §2.1 data-flow,
§9.2 posting, §10 storage). **Never silent-drop** (§9.3 / §10).

### Capacity: ≥24 h of outbound FHIR observations
The SQLite queue must hold **at least 24 h** of un-posted Observations. At the
aggregate cadence (~4 samples/s/device → ~4 Observations/s, ~400–600 B each
including FHIR envelope) that is ≈ 140 MB/device/day — trivially within the
Radxa/ROCKPro64's storage. `sbc/CLAUDE.md` §10.4 retains `samples` 30 days and
`observations` indefinitely, which **exceeds** the 24 h floor; this document
fixes **24 h of outbound (pending) Observations** as the hard minimum the SBC
deployment must guarantee (disk-provisioning check at install, §13).

### Idempotency & deduplication (every resource has a unique `Observation.identifier`)
Every Observation carries
`identifier = { system: "urn:rmms:seq", value: "<uuid>-<sensor>-<seq>" }`
(`sbc/CLAUDE.md` §8.6). The `<seq>` is the firmware's per-topic envelope
sequence number (§9.2.1). This is the single value that makes a measurement
**globally and stably identifiable** across every retry and replay.

### Server-side handling (update-or-ignore, never duplicate)
The SBC POSTs a `Bundle` of `transaction` type whose entries use **conditional
update / create**: `PUT [base]/Observation?identifier=urn:rmms:seq|<uuid>-<sensor>-<seq>`
(equivalently `If-None-Exist`). A FHIR R4 server that honours conditional
semantics will **update or ignore** a resource with a pre-existing identifier
instead of creating a duplicate (`sbc/CLAUDE.md` §8.6, §9.2). **The receiving
FHIR server must enforce this on `Observation.identifier`** — it is a deployment
requirement on the endpoint, documented here for the integration team.

### Ambient data → LOINC **or** SNOMED CT, explicitly documented
### Medical measurements → **strictly LOINC** in `Observation.code`
The mapping table is authoritative in `sbc/CLAUDE.md` §8.2. Summary:

| Field | Class | Code system | Code | Unit | Status |
|---|---|---|---|---|---|
| `heart_bpm` | medical (vital) | **LOINC** | `8867-4` | `/min` | verified |
| `breath_bpm` | medical (vital) | **LOINC** | `9279-1` | `/min` | verified |
| `hum_pct` | ambient | **LOINC** | `19736-7` | `%` | verified |
| `presence` | medical | placeholder `urn:rmms:obs-code` | `presence` | (boolean) | verify (no verified LOINC) |
| `temp_c` | ambient | placeholder `urn:rmms:obs-code` | `ambient_temp_c` | `Cel` | verify (8310-5 is *body* temp) |
| `pres_hpa` | ambient | placeholder `urn:rmms:obs-code` | `atmospheric_pressure_hpa` | `hPa` | verify (3140-1 is *body surface area*) |
| `co2_ppm` | ambient (air) | placeholder (LOINC **or SNOMED CT**) | `co2_ppm` | `ppm` | verify |
| `tvoc_ppb` | ambient (air) | placeholder (LOINC **or SNOMED CT**) | `tvoc_ppb` | `ppb` | verify |
| `aqi` | ambient (air) | placeholder (LOINC **or SNOMED CT**) | `uba_aqi` | (index 1–5) | verify |
| `lux` | ambient | placeholder `urn:rmms:obs-code` | `ambient_lux` | `lx` | verify |
| `distance_mm` | device meta | placeholder `urn:rmms:obs-code` | `subject_distance` | `mm` | verify |

Rule, per the requirements: **medical/vital fields use LOINC** — `heart_bpm` and
`breath_bpm` carry verified LOINC codes. **Ambient fields use a verified LOINC
where one exists** (`hum_pct`), **else a flagged placeholder** (`urn:rmms:obs-code`,
`confirmed=False`) pending a LOINC/SNOMED assignment. The remaining rows have no
*verified* code yet and **require clinical-advisor sign-off** before deployment —
they are flagged, never invented, and a real-but-wrong LOINC is never shipped
(an adversarial review caught `76689-9`/`3140-1` being mis-applied — see
`sbc/CLAUDE.md` §8.2). The safety invariant is asserted in the test suite
(`test_no_unverified_loinc_is_shipped`).

### All vitals + environmental metrics → HL7 FHIR R4 `Observation`
Every measurement becomes exactly one FHIR R4 `Observation` (one per value;
radar's heart/breath/presence are separate Observations), built with
`fhir.resources` Pydantic models so validation happens at construction
(`sbc/CLAUDE.md` §8.1, §8.3, §9.3). Quality → status: `0→final`,
`1/2→preliminary`, `3→dead-letter` (§8.4); a `-1` `wall_ms` forces `preliminary`
(§8.4/§8.5).

---
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

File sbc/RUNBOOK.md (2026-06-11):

# SBC bring-up runbook

Turnkey steps to install the SBC aggregator, run its tests, and **prove its
output is correct HL7 FHIR R4 — without a hospital server.** Run everything from
the `sbc/` directory.

The scope here is the project goal: *get the data into the correct FHIR API
standard format.* No real hospital/EHR, no OAuth — a local reference FHIR server
(HAPI) stands in for format validation only.

```
cd sbc
```

---

## Prerequisites (Pine64 / Radxa, Ubuntu aarch64)

```bash
sudo apt update && sudo apt install -y python3 python3-venv python3-pip
# Docker is only needed for Part 2 (local HAPI):
#   sudo apt install -y docker.io docker-compose-plugin
python3 --version    # need >= 3.11
```

---

## Part 0 — Zero-install sanity check (works on any machine)

The pure decision logic (FHIR mapping, codes, identifiers, R4 shape) has **no
third-party dependencies**, so you can confirm it before installing anything:

```bash
PYTHONPATH=src python3 -m unittest discover -s tests/pure -t tests/pure
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

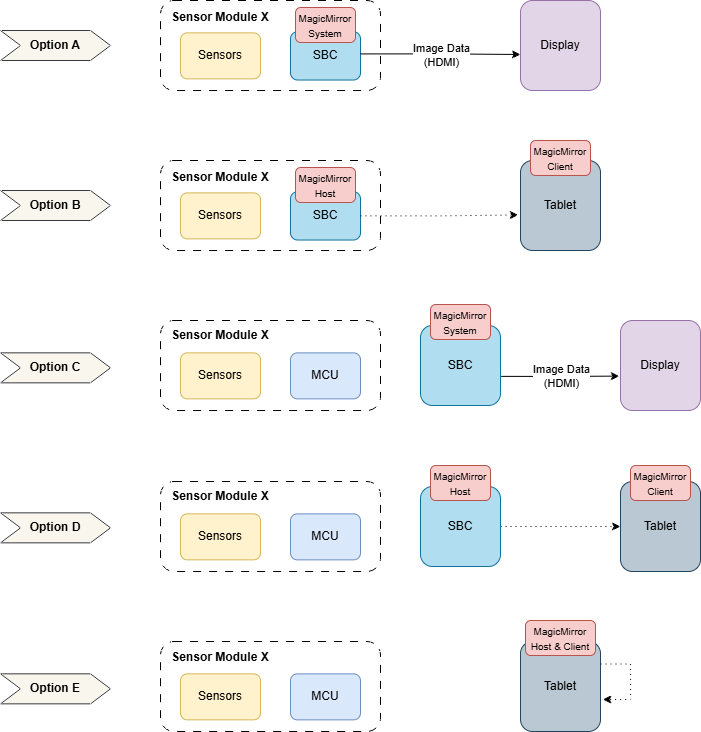
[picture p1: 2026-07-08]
documents_and_diagrams/diagrams/mm2 hardware options.drawio.png

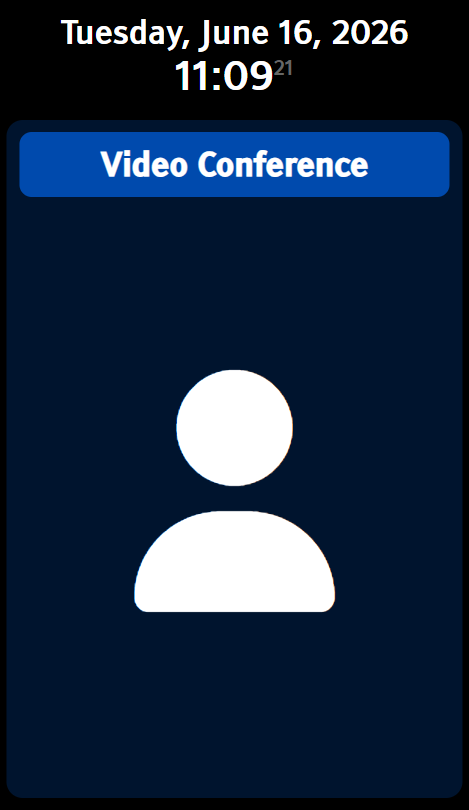
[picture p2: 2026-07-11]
MagicMirror/modules/MMM-VidConf/uiDesignVidConf.png

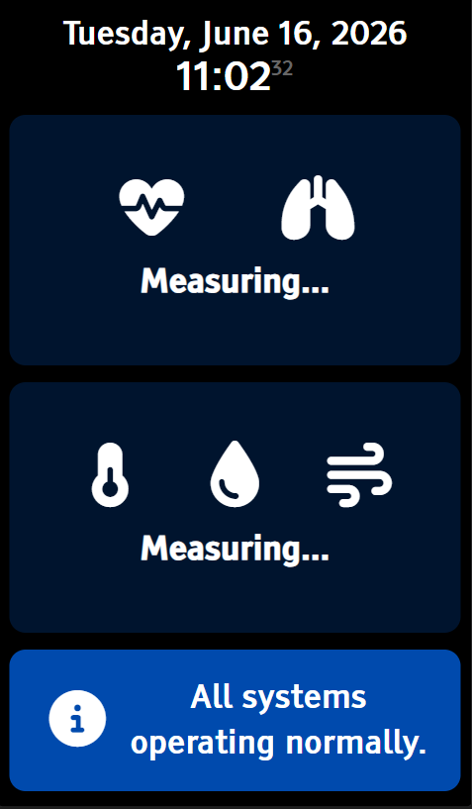
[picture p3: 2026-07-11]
MagicMirror/modules/MMM-SensorUI/uiDesignMeasuring.png

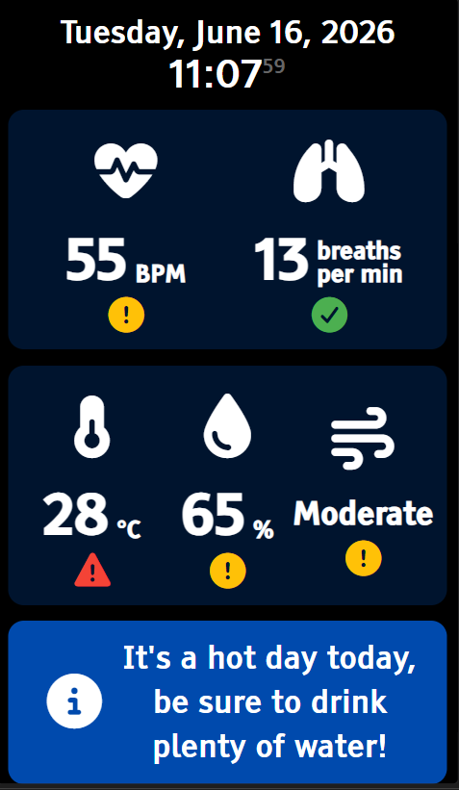
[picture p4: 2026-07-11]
MagicMirror/modules/MMM-SensorUI/uiDesignData.png

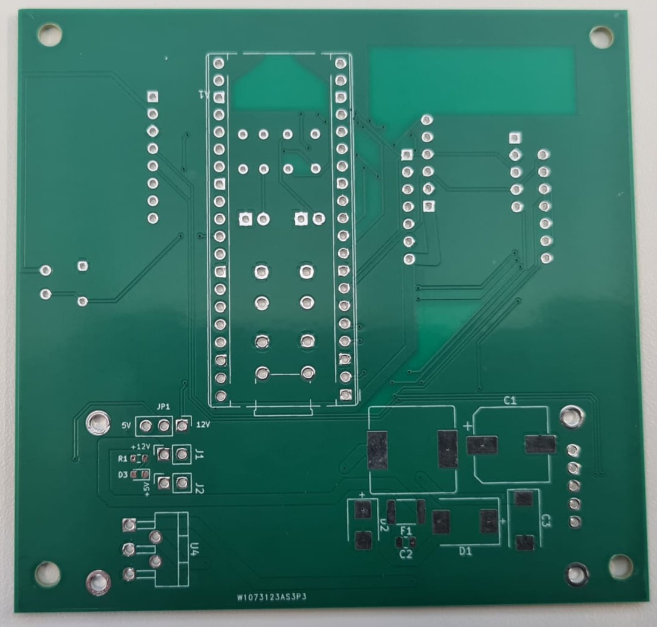
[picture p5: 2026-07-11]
PCB/PCB Design/KiCad files/Mirror PCB/Plots for rapport/PCB_Real_Back.jpeg

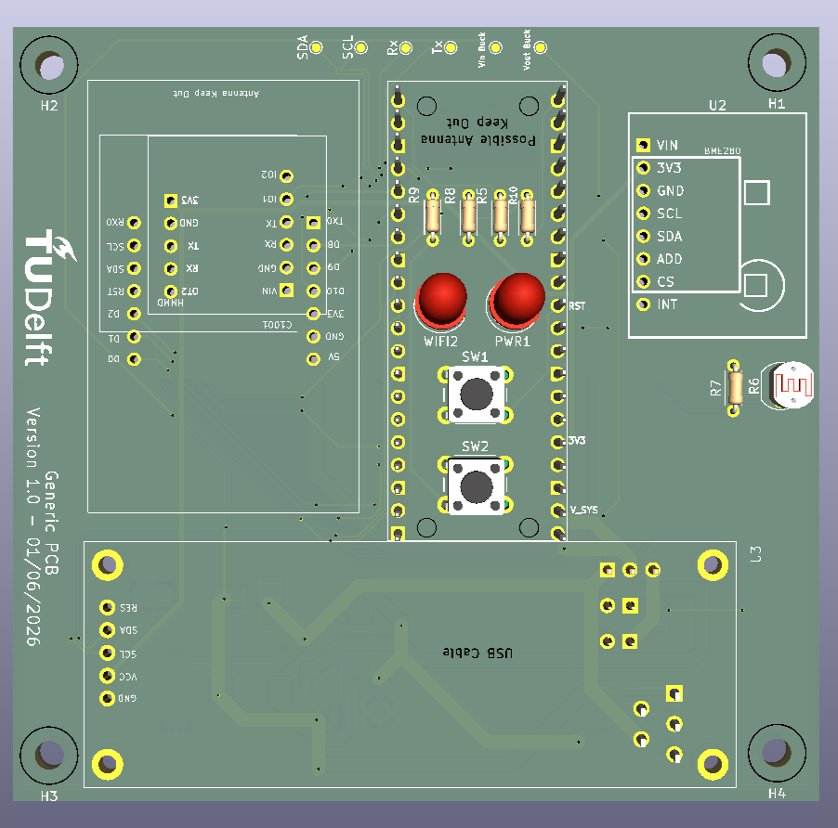
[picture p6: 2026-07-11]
PCB/PCB Design/KiCad files/Mirror PCB/Plots for rapport/Generic PCB_3D.png

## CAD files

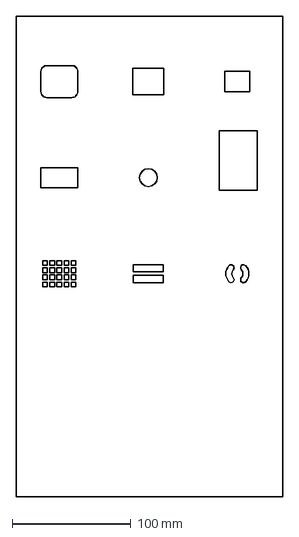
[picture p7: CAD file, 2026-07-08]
lasercutting_files/testcuts_radarsensors.dxf
225.0 x 405.0 mm

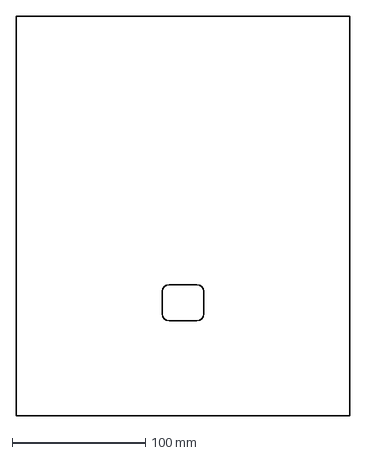
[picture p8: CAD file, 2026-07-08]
lasercutting_files/finalcut_rounded_rectangle.dxf
250.0 x 300.0 mm

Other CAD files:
lasercutting_files/designing_cuts_acrylic_plates.f3d

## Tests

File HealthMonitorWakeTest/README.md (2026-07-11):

# HealthMonitorWakeTest — tablet screen wake/lock app

Android app for the RMMS tablet. It couples radar presence to the tablet screen:
the MagicMirror² display behind the two-way acrylic lights up when someone is in
front of the mirror and locks (blanks) when nobody is there.

The app itself is deliberately dumb: it subscribes to one local MQTT topic and
turns the screen on or off. All presence *policy* (debounce, ghost filtering,
stale-radar handling) lives in `scripts/tablet_presence_screen.py`, which runs
on the same tablet in Termux. The authoritative design doc for the whole
coupling is **`docs/presence_screen_coupling.md`** — read that first.

## Role in the system

```
firmware radar ──rmms/<uuid>/radar (mTLS :8883)──► tablet_presence_screen.py
                                                        │ debounce / state machine
                                                        ▼
                                        `display` topic, plain MQTT 127.0.0.1:1883
                                                        │
                                                        ▼
                                              this app (MQTTService)
                                     "ON"  → WakeService full wakelock (screen on)
                                     "OFF" → DevicePolicyManager.lockNow() (screen off)
```

The firmware never talks to this app directly; it only publishes raw topics on
the mTLS listener. The bridge script is the adapter between the two worlds.

## MQTT contract (what the code actually does)

- Broker: `tcp://127.0.0.1:1883` — the **localhost-only plain listener** of the
  tablet's Mosquitto. This is deliberate on-device IPC, not a network-facing
  plaintext broker; see `docs/adr/0004-localhost-plain-listener-app-ipc.md` for
  why this does not violate the "mTLS-only" rule (the `:1883` listener is bound
  to `127.0.0.1` and carries no firmware traffic).
- Client: Eclipse Paho `org.eclipse.paho.client.mqttv3` 1.2.5, random client
  id, clean session, automatic reconnect, plus its own retry-every-5 s loop
  until the first connect succeeds.
- Subscription: topic **`display`** (no wildcard, no `rmms/` prefix).
- Payloads: plain strings, trimmed and uppercased before matching:
  - `ON` — starts `WakeService`, which acquires a
    `FULL_WAKE_LOCK | ACQUIRE_CAUSES_WAKEUP` wakelock for 5 s to turn the
    screen on.
  - `OFF` — calls `DevicePolicyManager.lockNow()` via the
    `MyDeviceAdminReceiver` device admin (policy `<force-lock/>`). If Device
    Admin is not active it logs an error and does nothing.
  - Anything else is logged and ignored.
- The app publishes nothing to the broker. It broadcasts status strings on an
  in-app `MQTT_MESSAGE` intent, shown in `MainActivity`'s status text.

`MainActivity` is a minimal test UI: manual SCREEN ON / SCREEN OFF buttons and
the last-MQTT-message text. Opening it also starts `MQTTService`.

## Build

The Android Studio project is **nested one level down**: open
`HealthMonitorWakeTest/HealthMonitorWakeTest/` (the folder containing
`settings.gradle.kts`), not this folder.

Command line:

```bash
cd HealthMonitorWakeTest/HealthMonitorWakeTest
./gradlew assembleDebug
# APK: app/build/outputs/apk/debug/app-debug.apk
```

Targets SDK 36, minSdk 26. A prebuilt APK is checked in at the repo root as
`apk/appScreenControl.apk`.

## Install + first run

1. Install the APK (`adb install` or sideload).
2. Open the app once so `MQTTService` starts.
3. **Grant Device Admin** — required for `lockNow()`; without it `OFF` does
   nothing. The app declares the admin receiver but does not prompt for it, so
   enable it manually: Settings → Security → Device admin apps →
   HealthMonitorWakeTest (or via adb:
   `adb shell dpm set-active-admin com.example.healthmonitorwaketest/.MyDeviceAdminReceiver`).
4. **Disable battery optimization** for the app (Settings → Battery), otherwise
   Android may kill the foreground MQTT service. The app does not request this
   exemption itself.
5. Start-on-boot works via `BootReceiver` (`BOOT_COMPLETED` /
   `QUICKBOOT_POWERON` → `startForegroundService(MQTTService)`). Note that
   Android only delivers `BOOT_COMPLETED` to apps the user has launched at
   least once.
6. Smoke test without radar, from Termux on the tablet:
   `mosquitto_pub -h 127.0.0.1 -p 1883 -t display -m ON` (screen wakes),
   `-m OFF` (screen locks).

The other half of the coupling — Mosquitto with both listeners (`:8883` mTLS +
`:1883` loopback plain), the mirror reader cert, and
`tablet_presence_screen.py` — is deployed by `scripts/demo_start.sh`; see the
design doc.

## Known operational gotchas (project findings)

- **Keep the tablet awake enough for the broker.** The screen-off part of this
  coupling works (`lockNow()` blanks the display), but if the tablet is allowed
  to actually sleep, Android Doze kills Mosquitto and sshd in Termux and the
  hotspot IP can drift — taking down the whole system, not just the mirror. In
  practice: battery optimization off for Termux and this app, and keep the
  device on power.
- **Radar ghost presence from walls.** A wall ~2.5 m in the MR60BHA2's cone can
  produce sustained `presence:true` with `distance_mm:null` and `q:2`. The
  gating lives in `tablet_presence_screen.py`, which currently keys on raw
  `v.presence` and only drops `q==3` samples — so a `q:2` wall ghost keeps the
  screen on forever. If this bites, either clear the radar's field of view
  (moving the wall/repointing the sensor fixed it on the bench) or change the
  bridge to require `distance_mm != null` before counting presence. Do the fix
  in the bridge script, not in this app and not in the firmware.
- The `display` payloads are compared after `.trim().uppercase()`, so `on`,
  `ON `, etc. all work — but only the literal strings `ON`/`OFF` do anything.
- `MQTTService` uses a foreground notification ("MQTT Service Running"); if
  that notification is missing, the service is not running — reopen the app or
  reboot.

## Pointers

- `docs/presence_screen_coupling.md` — authoritative design doc (chain,
  debounce parameters, deployment, test procedure).
- `docs/adr/0004-localhost-plain-listener-app-ipc.md` — why the plain `:1883`
  loopback listener exists and its security boundary.
- `scripts/tablet_presence_screen.py` — the presence→ON/OFF bridge (the policy
  half of this coupling).

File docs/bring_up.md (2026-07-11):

# Bring-Up Procedure

Step-by-step hardware bring-up checklist. **Do not skip steps.** Each step
assumes the previous one works. This mirrors the bring-up ladder in root
`CLAUDE.md §15`; that section is authoritative.

> **v1 scope reminders (root `CLAUDE.md`):** Wi-Fi is the **sole transport**
> ([ADR-0002](adr/0002-wifi-sole-transport.md)) — there is no USB-CDC data link,
> no USB-MQTT bridge, and no transport-selector FSM. The wire and on-device
> storage format is **JSON** (`§9.2`/§11) — config/state files are `*.json`. The
> radar is the **MR60BHA2** (advanced module) or the **24 GHz HMMD** module
> (generic module, [ADR-0007](adr/0007-hmmd-radar-second-driver.md)), selected by
> `/cfg/sensors.json` `"radar"`; the advanced module is what this guide demos.
> There is **no IR camera**. Developer logs go to a single **USB-serial dev console**
> (`pico_stdio_usb`, `§12`), which is *not* a tablet data link.

---

## Prerequisites

- Raspberry Pi Pico 2 WH flashed via BOOTSEL or SWD.
- `PICO_SDK_PATH` set to a v2.x checkout of `raspberrypi/pico-sdk`.
- `arm-none-eabi-gcc` ≥ 13.2, CMake ≥ 3.22 on PATH.
- A second Pico flashed as `debugprobe` (or a Picoprobe) on SWD for step 1+.
- Host PC: Linux or WSL2. Native Windows toolchain not recommended.

### Build setup (run once)

```bash
git submodule update --init --recursive
mkdir build && cd build
cmake -DPICO_BOARD=pico2_w -DCMAKE_BUILD_TYPE=Debug ..
cmake --build . -j$(nproc)
```

Release builds: `-DCMAKE_BUILD_TYPE=RelWithDebInfo -DNDEBUG=1`. `scripts/build.sh`
wraps dependency resolution and produces `sensor_module.uf2` (real firmware) plus
the bring-up images under `test/bringup/`.

---

## Step 1 — Blink (bare metal, no FreeRTOS)

**Goal:** verify toolchain, BOOTSEL flash, and SWD connectivity.
(`test/bringup/blink.c`.)

Flash via BOOTSEL:

```bash
# Hold BOOTSEL while plugging in USB, then:
cp build/main/sensor_module.uf2 /run/media/$USER/RP2350/
```

Flash via SWD (picoprobe attached):

```bash
openocd -f interface/cmsis-dap.cfg -f target/rp2350.cfg \
        -c "adapter speed 5000" \
        -c "program build/main/sensor_module.elf verify reset exit"
```

**Pass:** onboard LED blinks at 1 Hz.

---

## Step 2 — FreeRTOS hello (one task)

**Goal:** verify SMP boot, scheduler starts, no startup hang.
(`test/bringup/freertos_hello.c`.) One task blinks at 1 Hz via `vTaskDelay`.

**Pass:** LED blinks; no hard fault; scheduler runs.

---

## Step 3 — Dev-console logs

**Goal:** `LOG_I` output visible over the standalone USB-serial dev console
(`pico_stdio_usb`, root `CLAUDE.md §12`). (`test/bringup/usb_console.c`.)

```bash
minicom -D /dev/ttyACM0 -b 115200    # check `dmesg | tail` for the actual node
```

Add `LOG_I("hello tick %lu", (unsigned long)tick)` to the task loop.

**Pass:** log lines appear at 1 Hz. (This is a debug console, not a data link —
there is no CDC0/CDC1 split in v1.)

---

## Step 4 — littlefs mount

**Goal:** verify flash mount and KV read/write.
(`test/bringup/storage_counter.c`.)

```c
err_t err = storage_mount();
assert(err == ERR_OK);

uint32_t count = 0; size_t len = 0;
storage_read("/state/boot_count.json", &count, sizeof(count), &len);
count++;
storage_write_atomic("/state/boot_count.json", &count, sizeof(count));
LOG_I("Boot count: %lu", (unsigned long)count);
```

**Pass:** boot count increments each power cycle; no FS corruption over 10 cycles.

---

## Step 5 — Environment (AHT21 or BMP280)

**Goal:** `env_task` drives the `env_driver_t` v-table and publishes JSON samples
to a local debug sink (not yet MQTT). Selected via `/cfg/sensors.json` `"env"`
(`"aht21"` | `"bmp280"`; legacy `"bme280"` accepted as an alias).
(`test/bringup/bmp280_only.c`, `test/bringup/aht21_only.c`.)

- Verify I²C0 wiring (GP8 SDA / GP9 SCL) and pull-ups.
- Log each sample; validate the `snprintf` encoder, **including the
  `"pres_hpa": null` path when the AHT21 is selected** (no pressure sensor)
  **and the `"hum_pct": null` path when the BMP280 is selected** (no humidity
  sensor — the part is a BMP280, chip ID `0x58`, not a BME280).
- Expected: temp ~20–30 °C; humidity ~20–80 % (AHT21); pressure ~950–1050 hPa
  (BMP280).

**Pass:** 1 Hz samples with plausible values; `q=0`; no `ERR_IO`.

### Step 5b — ENS160 (air quality)

**Goal:** `air_task` publishes JSON `air` samples; writes the env driver's last
temp/hum into the ENS160 TEMP_IN/RH_IN compensation registers each cycle.
(`test/bringup/ens160_only.c`.) Confirm the ~5–10 min warm-up: during it the
driver reports `q=2` and AQI sits low until the gas heaters stabilise.

### Step 5c — BH1750 (light)

**Goal:** `light_task` publishes `{"lux":…}` at ~0.2 Hz (continuous H-res,
~120 ms/measurement; init does power-on + initial ~180 ms wait). I²C0 addr `0x23`.

---

## Step 6 — OLED

**Goal:** SH1122 (256×64) shows page 1 (status) and page 2 (last env sample);
the button cycles pages. (`test/bringup/oled_only.c`.)

- I²C0 address `0x3C` (SA0 low) / `0x3D`. Controller is SH1122 (confirmed,
  root `CLAUDE.md §16 Q1`).
- One user button on GP16 (active-low, internal pull-up); `ui_input_init()`.

**Pass:** pages cycle on press; env values update at 1 Hz; no I²C errors.

---

## Step 7 — mmWave radar (MR60BHA2)

**Goal:** Seeed binary protocol parsed; `presence`, `breath_bpm`, `heart_bpm`,
`distance_mm` decode into `RadarSample`. (`test/bringup/radar_only.c`.)

- Verify UART1 wiring (MCU TX GP5 → radar RX; MCU RX GP4 ← radar TX), 115200 baud,
  radar on its own 5 V rail.
- `/cfg/sensors.json` `"radar": "bha2"`.
- Wave/sit in front of the radar to trigger presence; log each `RadarSample`.

**Pass:**
- `presence=true` when a person is nearby.
- `breath_bpm` / `heart_bpm` plausible with a person present.
- `q=0` on good samples; `q=2` on ghost readings (presence without vitals).
- Framing confirmed on the bench (root `CLAUDE.md §3.2`): SOF-`0x01` 8-byte
  header + `~XOR` checksums — **not** Andar `0x53 0x59` framing.

The plausibility/median/breath-hold post-processing on top of the driver is
[ADR-0005](adr/0005-mcu-side-radar-filtering.md) / [ADR-0006](adr/0006-phase-based-breath-hold-detection.md).

### Step 7b — HMMD radar variant + selection (generic module, ADR-0007)

**Goal:** the same firmware drives the Waveshare HMMD (24 GHz) module with no
rebuild — just a config flag. Only relevant on a board populated with the HMMD
part. Protocol is the previous group's reference driver
(`bestanden_vorige_BAP/.../lib/hmmd_mpy.py` — tree removed at handover, retrieve from pre-July-2026 git history; CLAUDE.md §18): `F4 F3 F2 F1`
header, LE length, `presence + distance + 16 gate energies`, `F8 F7 F6 F5` tail,
no checksum. `init` sends the Report-Mode command first.

- Set `/cfg/sensors.json` `"radar": "hmmd"`; power-cycle.
- On boot the log shows `Radar driver selected: 24 GHz HMMD` and
  `init OK … (HMMD report-mode protocol)` — confirms `radar_select_from_config()`
  picked the right driver with no code change (same `RadarSample` → same
  `rmms/<uuid>/radar`).
- Wave/sit in front of the radar; `presence=true`, `distance_mm` tracks range.

**Pass:**
- Correct driver name in the startup `LOG_I`; `"bha2"` vs `"hmmd"` swaps drivers
  with no rebuild.
- `presence` and `distance_mm` are live. `heart_bpm`, `breath_bpm`, and
  `resp_motion` are **always `null`** — the HMMD has no respiration/heart
  sensing (graceful degradation, ADR-0007), not a fault.
- **TODO(spec):** confirm the distance **unit** against a tape measure — the
  reference used a 0.7 m gate factor, the driver assumes cm→mm
  (`HMMD_DIST_MM_PER_RAW`); adjust and strip the marker. The frame envelope
  (`F4 F3 F2 F1 … F8 F7 F6 F5`) is already host-tested
  (`test/host/test_radar_hmmd.c`).

---

## Step 8 — Light sensor (GL5516 LDR variant)

**Goal:** ADC sampling + power-law calibration for the *generic*-module variant
(`/cfg/sensors.json` `"light": "gl5516"`).

- GP26 / ADC0 wired to the divider midpoint: `3V3 ─ LDR(GL5516) ─ node ─ 1 kΩ ─ GND`.
- Cover/uncover the LDR; verify lux changes in the `light` sample.
- Same `{"lux":…}` payload as the BH1750 path (ADR-0001).

**Pass:** ~0.2 Hz samples with plausible lux.

---

## Step 9 — CYW43 + lwIP

**Goal:** Wi-Fi DHCP, ping, and mDNS resolve of `tablet.local`.
(`test/bringup/wifi_connect.c`.)

- Provision `/cfg/wifi.json` (SSID, PSK, country) and `/cfg/broker.json`
  (`{"host":"tablet.local","ip":"","port":8883}`).
- `cyw43_arch_init_with_country(CYW43_COUNTRY_NETHERLANDS)`.
- `dns_gethostbyname("tablet.local")` routes to a multicast query
  (`LWIP_DNS_SUPPORT_MDNS_QUERIES`); the tablet's responder
  (`scripts/tablet_mdns_responder.py`) answers (root `CLAUDE.md §8.2`).

```bash
ping <pico-ip>            # from the host, confirm the Pico is on the LAN
```

**Pass:** DHCP assigned; ping succeeds; `tablet.local` resolves. (Campus eduroam
blocks device↔tablet P2P/multicast — use a phone hotspot, keep the tablet awake.)

---

## Step 10 — mbedTLS over TCP (Wi-Fi)

**Goal:** first TLS handshake to Mosquitto via Wi-Fi. This establishes the single
mbedTLS config (static cert chain, restricted cipher suites — root
`CLAUDE.md §10.2`) the rest of the stack reuses. (`test/bringup/mqtt_connect.c`,
`lwip` harness.)

- Uses lwIP's `altcp_tls` (mbedTLS); there is no custom `stream_t`/BIO shim.
- Cert chain from littlefs `/certs/{dev.crt,dev.key,ca.der}` (DER).

**Pass:**
- TLS handshake succeeds over Wi-Fi within ~1 s (root `CLAUDE.md §14.2`).
- Device cert accepted by the broker CA; broker cert validated by the device.

---

## Step 11 — Wi-Fi transport (`transport_task`)

**Goal:** `transport_mqtt` brings up Wi-Fi → `altcp_tls` → lwIP MQTT, gets
CONNACK, publishes, and reconnects with backoff (1 s → 32 s) on link loss. There
is **no transport FSM** in v1 (ADR-0002). (`test/bringup/sensors_publish.c`.)

- Publishes `rmms/<uuid>/status = "online"` (retained, QoS 1) on CONNACK; LWT
  `"offline"`.
- Every sample is spooled (ADR-0003) and drained QoS-1 retry-until-PUBACK.

```bash
# From the host, subscribe with the mirror (or a device) cert bundle:
mosquitto_sub -h tablet.local -p 8883 \
    --cafile ~/rmms-ca/ca.crt --cert out/mirror-*/cert.pem --key out/mirror-*/key.pem \
    -t 'rmms/#' -v
```

**Pass:** CONNACK observed; `status=online` and sensor samples arrive; a Wi-Fi
drop recovers within the backoff window (fresh TLS handshake).

---

## Step 12 — End-to-end identity check

**Goal:** boot against the real tablet Mosquitto with the production ACL pattern.
(`scripts/test_broker_acl.sh <broker-ip>` automates the assertions.)

Broker (root `CLAUDE.md §9.4`/§16 Q9): `require_certificate true`,
`use_identity_as_username true`, ACL:

```
pattern write rmms/%u/#
pattern read  rmms/%u/cmd
```

Verify:
1. Client cert accepted; `client_id` == cert CN.
2. Device can publish `rmms/<uuid>/#` → succeeds.
3. Device cannot publish `rmms/<other-uuid>/#` → ACL-denied.
4. Device receives a `cmd` sent to `rmms/<uuid>/cmd`.

**Pass:** all four hold with **no per-device broker config**. (No handshake
protocol to test — just TLS + MQTT CONNECT + a publish + a subscribe.)

---

## Step 13 — 48-hour soak test

**Goal:** stability before any tag is cut.

```bash
mosquitto_sub -h <broker-ip> -p 8883 \
    --cafile ~/rmms-ca/ca.crt --cert out/mirror-*/cert.pem --key out/mirror-*/key.pem \
    -t 'rmms/#' | ts '[%Y-%m-%d %H:%M:%S]' | tee soak.log
```

During the soak:
- Log task stack high-water marks hourly; any growth is a leak until proven
  otherwise.
- Verify sample rates: env/air 1 Hz, radar at native rate, light ~0.2 Hz.
- Verify steady-state publish round-trip < 250 ms on Wi-Fi.

**Pass:** no unplanned disconnects in 48 h; no high-water-mark growth; queues +
spool drain without overflow (dropped-sample counter stable); no `ERR_IO`.

---

## Performance targets (root `CLAUDE.md §14.2`)

| Metric | Target (Wi-Fi) |
|---|---|
| First-connect handshake (TLS + MQTT CONNECT/CONNACK) | < 1 s |
| Steady-state sense-to-broker latency | < 1 s |
| MQTT publish round-trip (post-handshake) | < 250 ms |
| Sustained throughput | ≥ 700 B/s |

The TLS handshake cost is one-time per connection, not per message. If
steady-state latency is much worse than the previous group's plaintext-MQTT
baseline, something is wrong — it is not TLS. (USB-CDC targets from earlier
drafts are gone with the transport — ADR-0002.)

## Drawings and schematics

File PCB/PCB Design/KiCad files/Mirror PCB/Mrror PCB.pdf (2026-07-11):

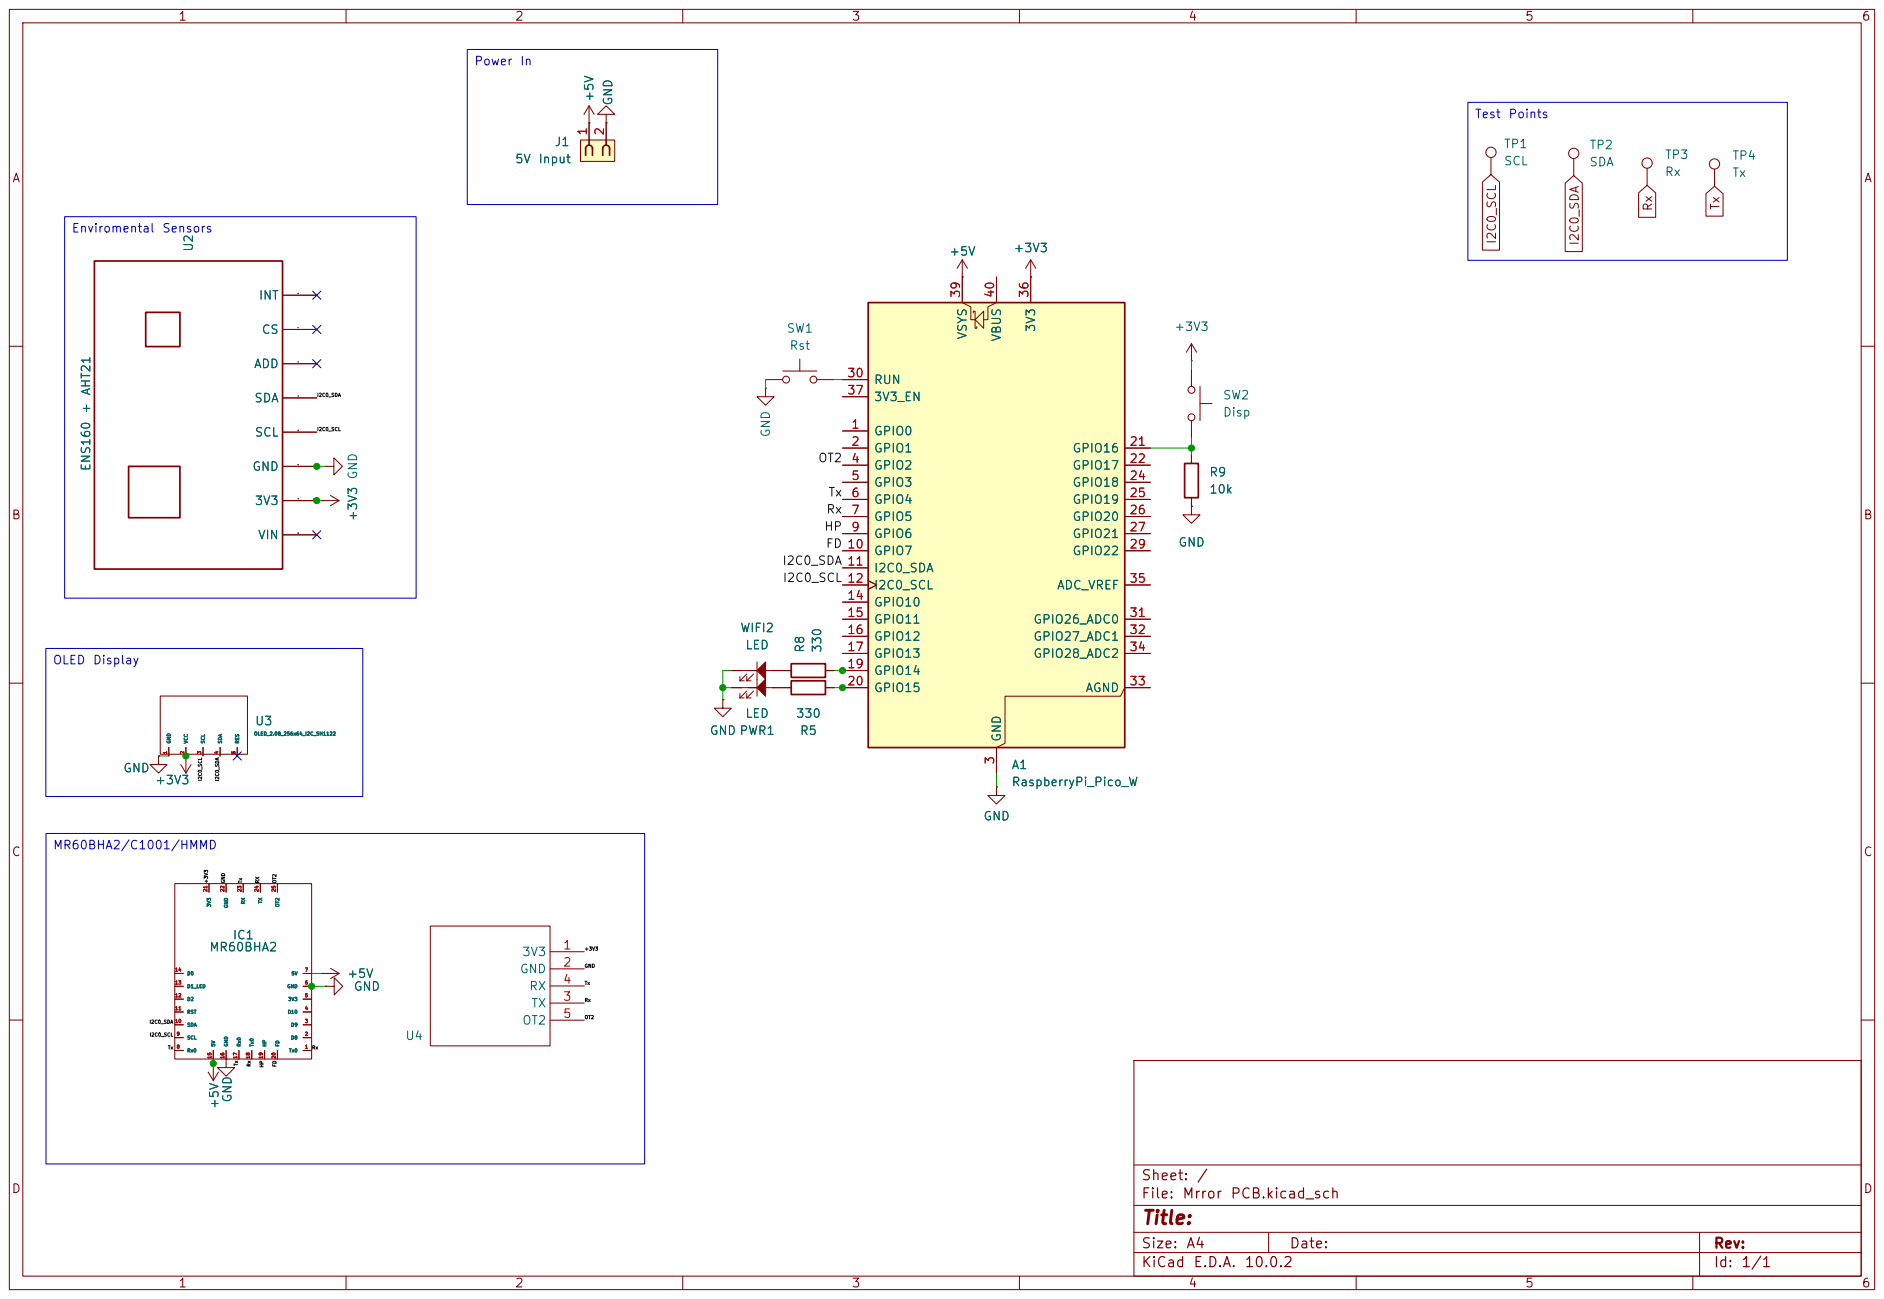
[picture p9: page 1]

Test Points Power In MR60BHA2/C1001/HMMD OLED Display Enviromental Sensors U2 ENS160 + AHT21
LED +5V GND

Size: A4 | Rev:
KiCad E.D.A. 10.0.2 | Id: 1/1

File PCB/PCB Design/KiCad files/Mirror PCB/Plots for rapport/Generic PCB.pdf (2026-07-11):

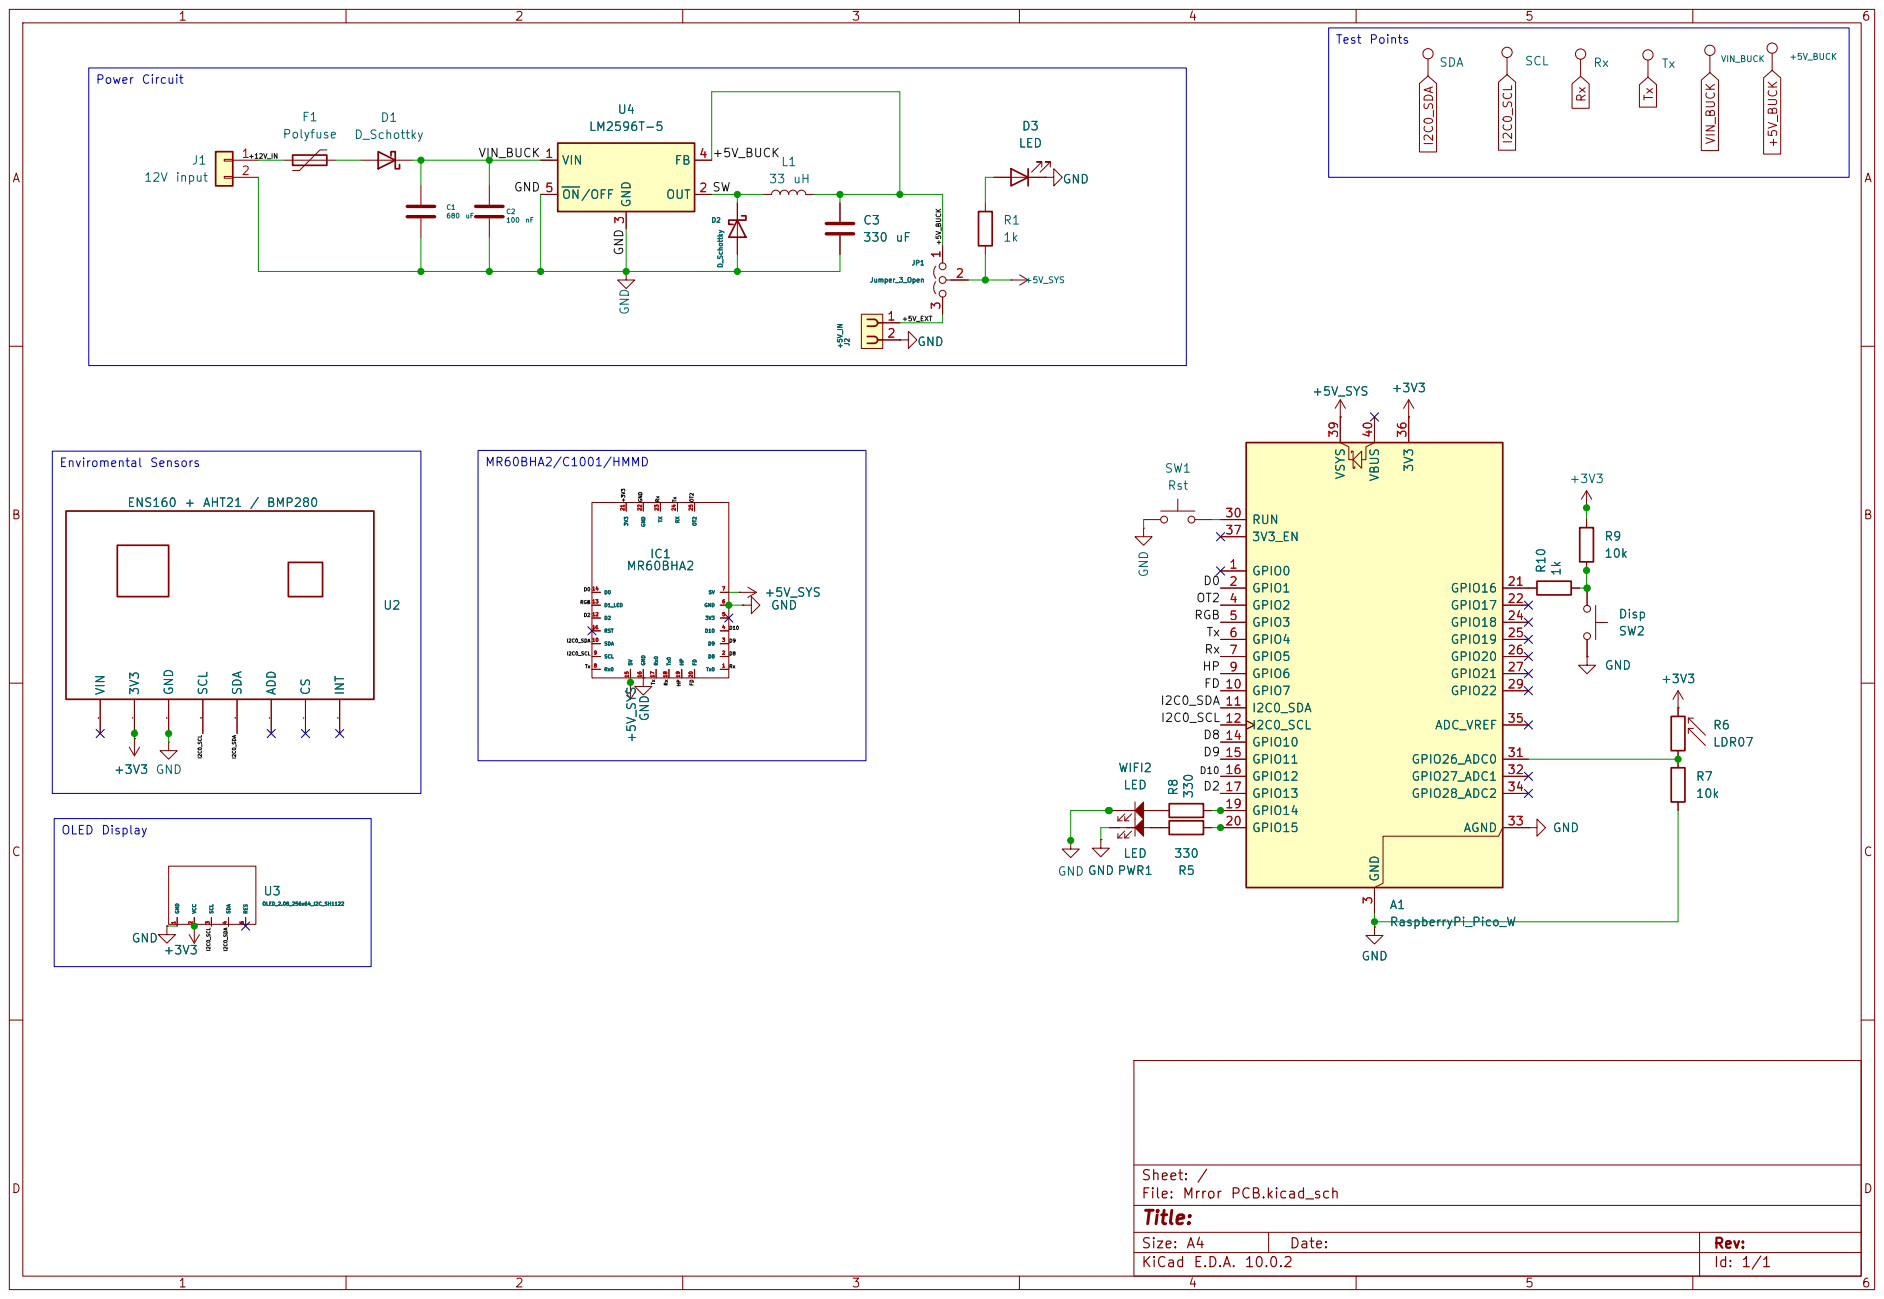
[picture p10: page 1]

Test Points OLED Display

Size: A4 | Rev:
KiCad E.D.A. 10.0.2 | Id: 1/1

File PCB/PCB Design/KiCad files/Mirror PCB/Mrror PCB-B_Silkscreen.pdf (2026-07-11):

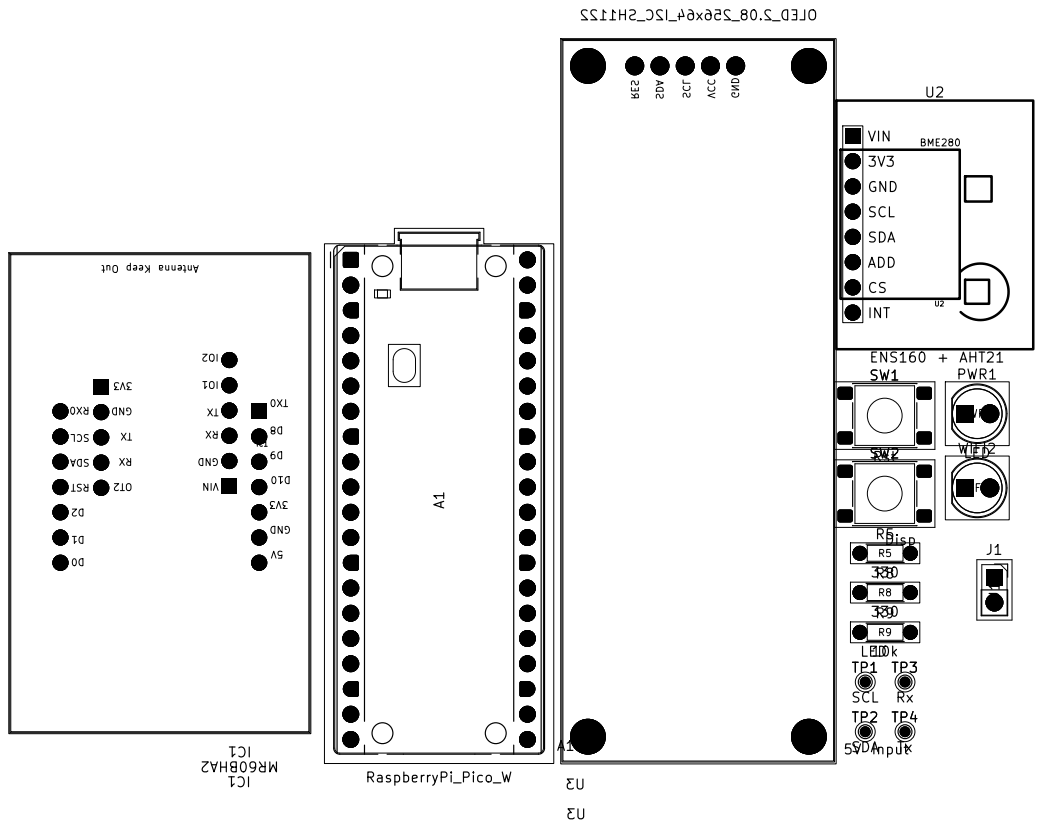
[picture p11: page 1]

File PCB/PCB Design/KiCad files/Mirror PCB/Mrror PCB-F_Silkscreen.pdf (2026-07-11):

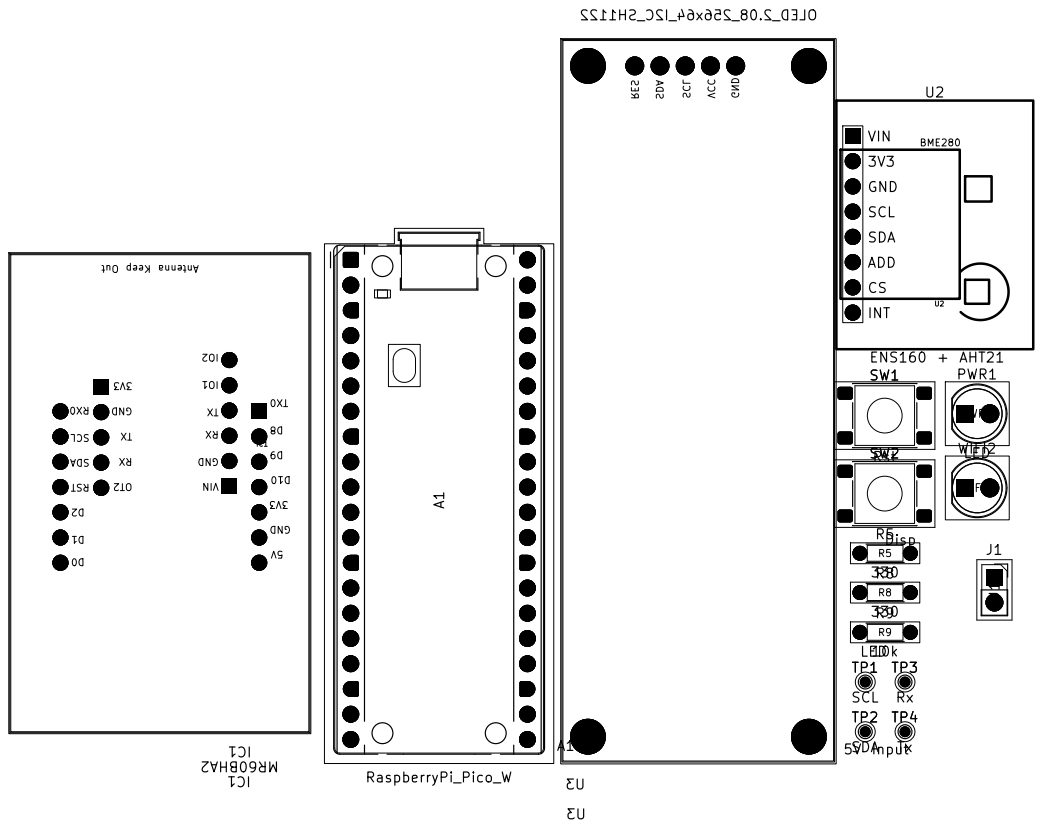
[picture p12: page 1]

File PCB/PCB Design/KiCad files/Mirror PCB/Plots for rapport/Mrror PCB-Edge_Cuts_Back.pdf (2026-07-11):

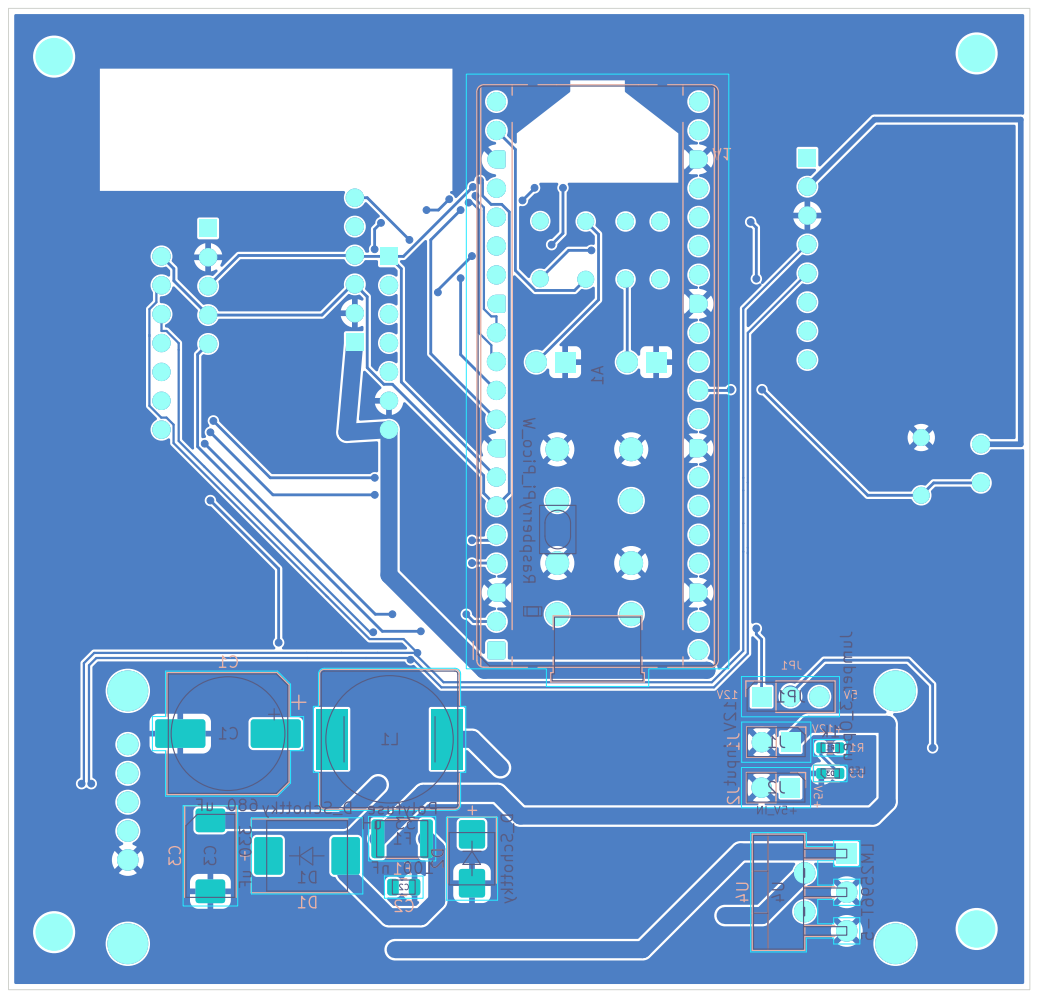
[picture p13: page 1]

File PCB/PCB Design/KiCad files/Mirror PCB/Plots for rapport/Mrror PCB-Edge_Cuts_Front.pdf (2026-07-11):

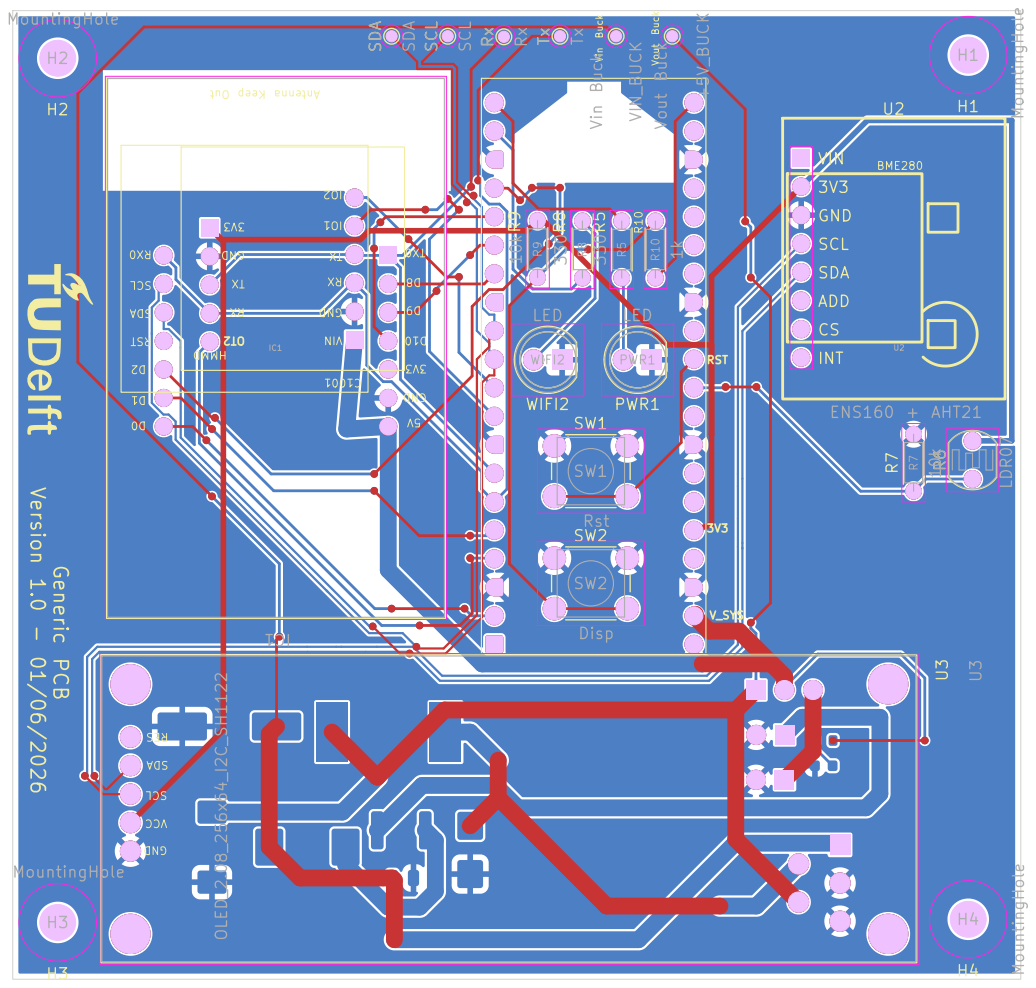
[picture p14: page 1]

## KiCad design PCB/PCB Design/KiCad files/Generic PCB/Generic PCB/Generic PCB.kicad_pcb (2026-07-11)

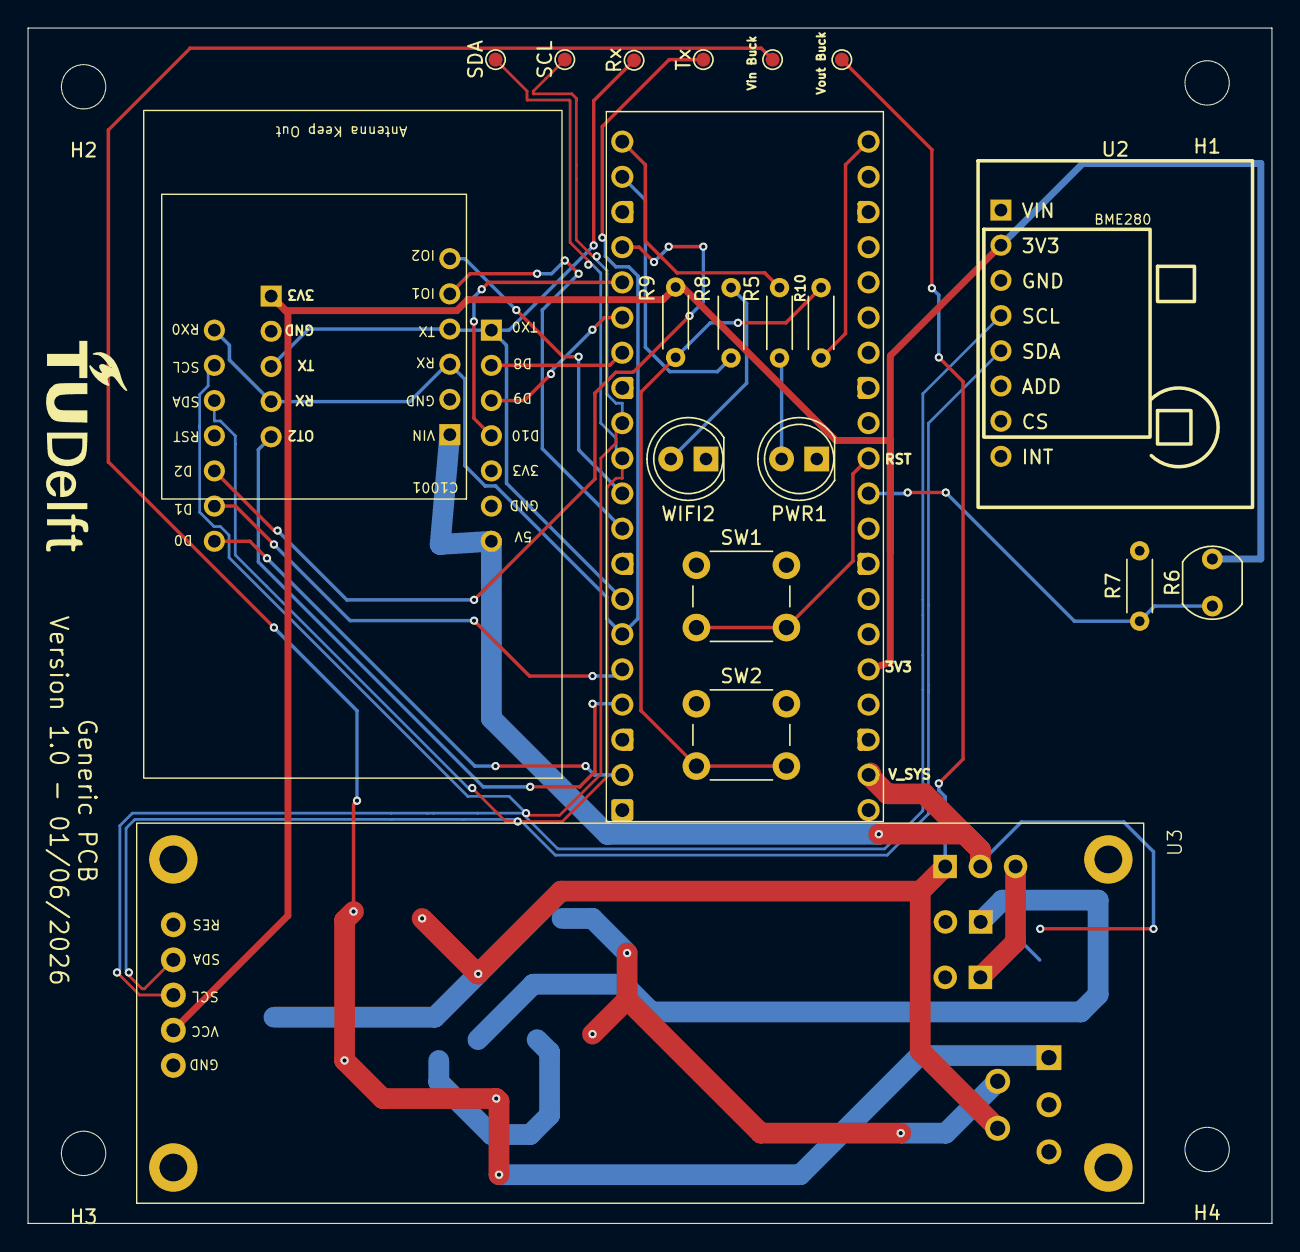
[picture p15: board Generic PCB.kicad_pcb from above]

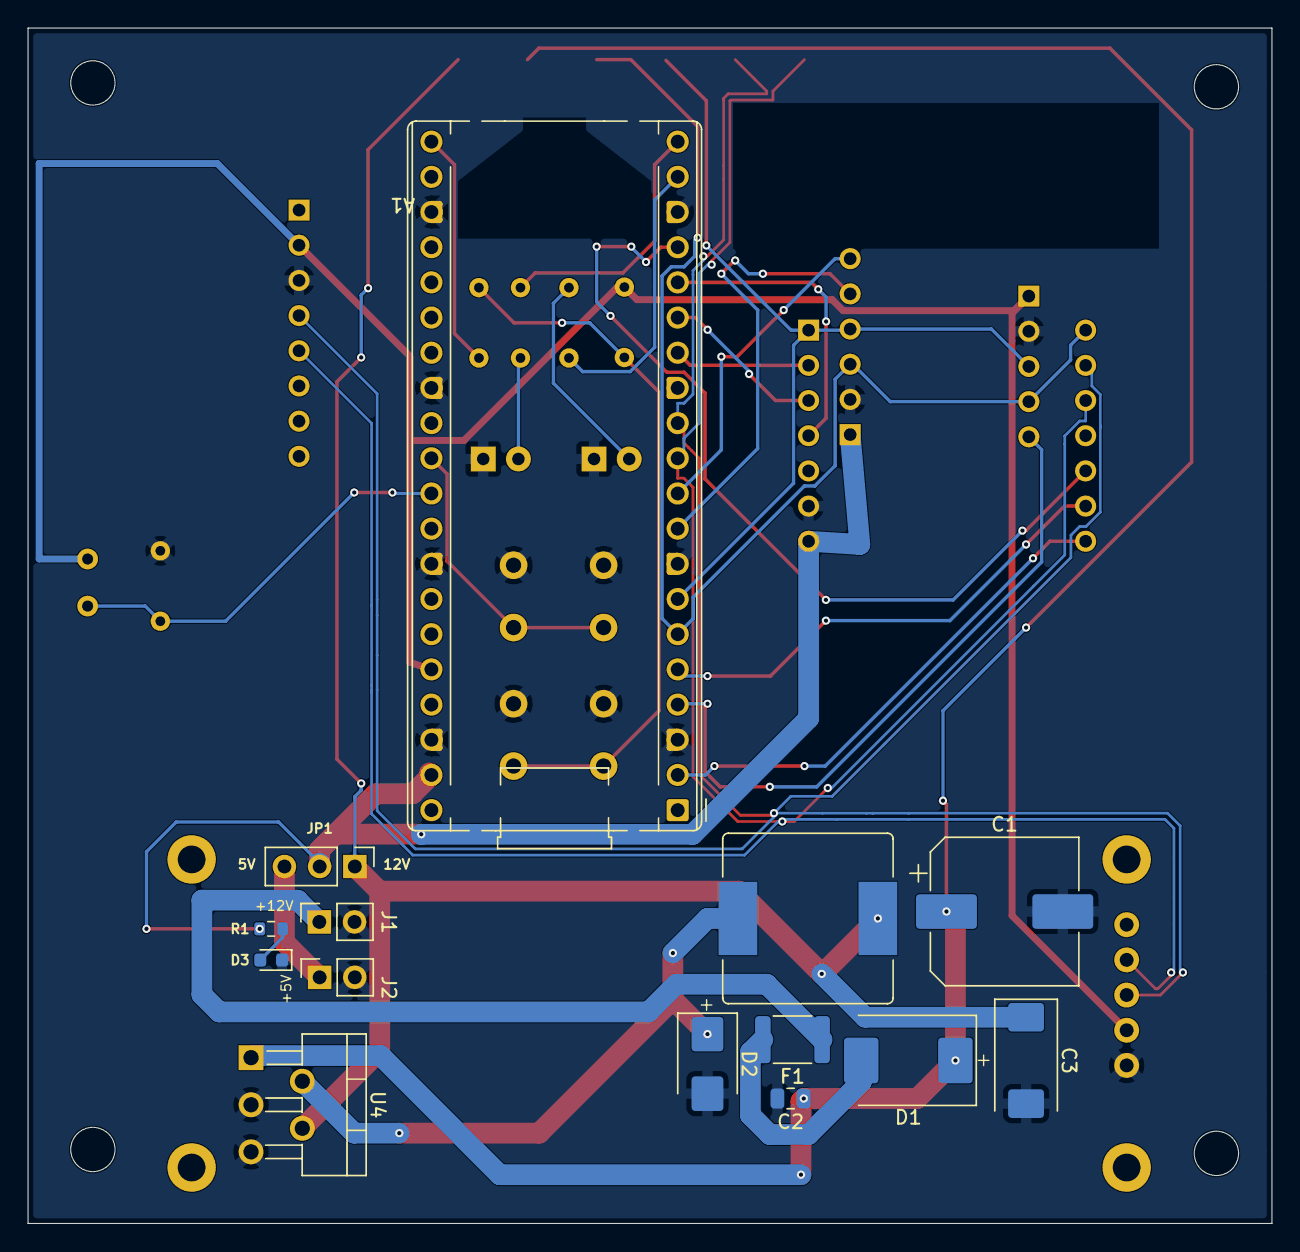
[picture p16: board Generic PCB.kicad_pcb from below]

Board: 2 copper layers, 89.8 x 86.3 mm, 37 parts (14 on the bottom side), 31 nets.

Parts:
A1: RaspberryPi_Pico_W; RaspberryPi_Pico_Common_THT
C1: 680 uF; CP_Elec_10x10.5
C2: 100 nF; C_0805_2012Metric
C3: 330 uF; CP_EIA-7343-31_Kemet-D
D1: D_Schottky; D_SMC
D2: D_Schottky; D_SMB
D3: LED; LED_0603_1608Metric
F1: Polyfuse; Fuse_1812_4532Metric
H1, H2, H3, H4: MountingHole; MountingHole_3.2mm_M3
IC1: MR60BHA2
J1: 12V input; PinSocket_1x02_P2.54mm_Vertical
J2: +5V_IN; PinSocket_1x02_P2.54mm_Vertical
JP1: Jumper_3_Open; PinHeader_1x03_P2.54mm_Vertical
L1: 33 uH; L_Bourns_SRR1210A
PWR1: LED; LED_D5.0mm
R1: 1k; R_0603_1608Metric
R5, R8: 330; R_Axial_DIN0204_L3.6mm_D1.6mm_P5.08mm_Horizontal
R6: LDR07; R_LDR_5.1x4.3mm_P3.4mm_Vertical
R7, R9: 10k; R_Axial_DIN0204_L3.6mm_D1.6mm_P5.08mm_Horizontal
R10: 1k; R_Axial_DIN0204_L3.6mm_D1.6mm_P5.08mm_Horizontal
Rx: Rx; TestPoint_Pad_D1.0mm
SCL: SCL; TestPoint_Pad_D1.0mm
SDA: SDA; TestPoint_Pad_D1.0mm
SW1: Rst; SW_PUSH_6mm
SW2: Disp; SW_PUSH_6mm
Tx: Tx; TestPoint_Pad_D1.0mm
U2: ENS160 + AHT21; ENS160+AHT21
U3: OLED_2.08_256x64_I2C_SH1122; OLED Display
U4: LM2596T-5; TO-220-5_P3.4x3.7mm_StaggerOdd_Lead3.8mm_Vertical
Vin Buck: VIN_BUCK; TestPoint_Pad_D1.0mm
Vout Buck: +5V_BUCK; TestPoint_Pad_D1.0mm
WIFI2: LED; LED_D5.0mm

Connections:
+3V3: A1.36 (3V3), IC1.21 (3V3), R6.2, R9.1, U2.2 (3V3), U3.2 (VCC)
+5V_BUCK: C3.1, JP1.1 (A), L1.2, U4.4 (FB), Vout Buck.1 (1_1)
+5V_SYS: A1.39 (VSYS), IC1.7 (5V), IC1.15 (5V), JP1.2 (C), R1.2
/+5V_EXT: J2.1, JP1.3 (B)
/+12V_IN: F1.1, J1.1
/D0: A1.2 (GPIO1), IC1.14 (D0)
/D2: A1.17 (GPIO13), IC1.12 (D2)
/D8: A1.14 (GPIO10), IC1.2 (D8)
/D9: A1.15 (GPIO11), IC1.3 (D9)
/D10: A1.16 (GPIO12), IC1.4 (D10)
/FD: A1.10 (GPIO7), IC1.20 (FD)
/HP: A1.9 (GPIO6), IC1.19 (HP)
/OT2: A1.4 (GPIO2), IC1.25 (OT2)
/RGB: A1.5 (GPIO3), IC1.13 (D1_LED)
/SW: D2.1 (K), L1.1, U4.2 (OUT)
GND: A1.3 (GND), A1.8 (GND), A1.13 (GND), A1.18 (GND), A1.23 (GND), A1.28 (GND), A1.33 (AGND), A1.38 (GND), C1.2, C2.2, C3.2, D2.2 (A), D3.1 (K), IC1.6 (GND), IC1.16 (GND), IC1.22 (GND), J1.2, J2.2, PWR1.1, R7.2, SW1.1, SW2.1, U2.3 (GND), U3.1 (GND), U4.3 (GND), U4.5 (~ON/OFF), WIFI2.1
I2C0_SDA+: A1.11 (I2C0_SDA), IC1.10 (SDA), SDA.1 (1_1), U2.5 (SDA), U3.4 (SDA)
I2C0_SDA-: A1.12 (I2C0_SCL), IC1.9 (SCL), SCL.1 (1_1), U2.4 (SCL), U3.3 (SCL)
unnamed: A1.19 (GPIO14), R8.2
unnamed: A1.20 (GPIO15), R5.1
unnamed: A1.21 (GPIO16), R10.1
unnamed: A1.31 (GPIO26_ADC0), R6.1, R7.1
unnamed: A1.30 (RUN), SW1.2
unnamed: D1.2 (A), F1.2
unnamed: D3.2 (A), R1.1
unnamed: PWR1.2, R5.2
unnamed: R8.1, WIFI2.2
unnamed: R9.2, R10.2, SW2.2
Rx: A1.7 (GPIO5), IC1.1 (Tx0), IC1.18 (Tx0), IC1.23 (TX), Rx.1 (1_1)
Tx: A1.6 (GPIO4), IC1.8 (Rx0), IC1.17 (Rx0), IC1.24 (RX), Tx.1 (1_1)
VIN_BUCK: C1.1, C2.1, D1.1 (K), U4.1 (VIN), Vin Buck.1 (1_1)

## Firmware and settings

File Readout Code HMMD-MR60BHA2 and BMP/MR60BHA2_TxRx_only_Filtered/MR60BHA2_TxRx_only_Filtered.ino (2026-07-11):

#include <Arduino.h>
#include <math.h>

// ============================================================
//  1. HARDWARE / UART SETTINGS
// ============================================================

// Pico 2 W UART pins
static const int RADAR_TX_PIN = 4;   // Pico GP0 -> Radar RX0
static const int RADAR_RX_PIN = 5;   // Pico GP1 <- Radar TX0

#define RADAR_SERIAL Serial2

// Optional reset pin. Leave as -1 if not connected.
static const int RADAR_RST_PIN = -1;

// Seeed examples often use 115200.
// If no valid frames are received, try 1382400.
static const uint32_t RADAR_BAUD = 115200;

// Print continuous phase values only for debugging.
static const bool PRINT_PHASES = false;

// Print raw values before filtering.
static const bool PRINT_RAW = false;


// ============================================================
//  2. RADAR FRAME PROTOCOL SETTINGS
// ============================================================

static const uint8_t SOF = 0x01;       // Start of frame byte
static const size_t HEADER_LEN = 8;    // Radar header length
static const size_t MAX_DATA_LEN = 64; // Maximum accepted payload size

uint8_t headerBuf[HEADER_LEN];
uint8_t dataBuf[MAX_DATA_LEN];

enum ParseState {
  WAIT_SOF,
  READ_HEADER,
  READ_DATA_AND_CHECKSUM
};

ParseState state = WAIT_SOF;

size_t headerIndex = 0;
size_t dataIndex = 0;

uint16_t dataLen = 0;
uint16_t frameType = 0;

uint32_t lastValidFrameMs = 0;


// ============================================================
//  3. FILTER SETTINGS
// ============================================================

// How often the filtered result is printed.
static const uint32_t OUTPUT_EVERY_MS = 1000;

// A radar frame older than this is considered stale.
static const uint32_t FRAME_STALE_MS = 2500;

// Presence must be detected continuously before being trusted.
static const uint32_t PRESENCE_CONFIRM_MS = 5000;

// Absence must also be stable before declaring no target.
static const uint32_t ABSENCE_CONFIRM_MS = 4000;

// Distance range used for vital-sign detection.

static const float MIN_DISTANCE_CM = 40.0f;
static const float MAX_DISTANCE_CM = 150.0f;

// Sudden distance changes larger than this restart validation.
static const float DISTANCE_MAX_JUMP_CM = 20.0f;

// Distance must remain stable for this duration.
static const uint32_t DISTANCE_CONFIRM_MS = 4000;

// EMA smoothing time constant for distance.
// Larger value = slower but smoother.
static const float DISTANCE_TAU_MS = 5000.0f;

static const uint32_t DISTANCE_TIMEOUT_MS = 5000;


// Heart-rate plausibility and smoothing settings
static const float MIN_HEART_BPM = 45.0f;
static const float MAX_HEART_BPM = 125.0f;
static const float HEART_MAX_JUMP_BPM = 8.0f;
static const uint32_t HEART_CONFIRM_MS = 5000;
static const float HEART_TAU_MS = 6000.0f;
static const uint32_t HEART_TIMEOUT_MS = 6000;


// Breathing-rate plausibility and smoothing settings
static const float MIN_BREATH_RATE = 0.0f;
static const float MAX_BREATH_RATE = 30.0f;
static const float BREATH_MAX_JUMP = 3.0f;
static const uint32_t BREATH_CONFIRM_MS = 5000;
static const float BREATH_TAU_MS = 6500.0f;
static const uint32_t BREATH_TIMEOUT_MS = 6000;


// Optional calibration offsets.
// Keep these at 0 unless you have validated a consistent bias.
static const float HEART_CALIBRATION_OFFSET_BPM = -12.0f;
static const float BREATH_CALIBRATION_OFFSET = -2.0f;


// ============================================================
//  4. FINAL ONE-MINUTE ESTIMATE SETTINGS
// ============================================================

// The final estimate is calculated after one minute of stable data.
static const uint32_t ESTIMATE_WINDOW_MS = 20000;

// Collect one filtered sample per second.
static const uint32_t ESTIMATE_SAMPLE_EVERY_MS = 1000;

static const int ESTIMATE_MAX_SAMPLES = 20;
static const int ESTIMATE_MIN_SAMPLES = 15;

// Outlier rejection strength.
// Smaller = stricter, larger = more tolerant.
static const float ESTIMATE_OUTLIER_K = 2.5f;

// Prevent divide-by-zero when all samples are nearly identicRal.
static const float MIN_ROBUST_SIGMA = 0.5f;


// ============================================================
//  5. RAW LATEST RADAR VALUES
// ============================================================

// These are the newest decoded values from the radar.
// They are not trusted immediately.

bool rawHumanDetected = false;
uint32_t lastHumanFrameMs = 0;

bool rawDistanceValid = false;
float rawDistanceCm = 0.0f;
uint32_t lastDistanceFrameMs = 0;

float rawHeartBpm = 0.0f;
uint32_t lastHeartFrameMs = 0;

float rawBreathRate = 0.0f;
uint32_t lastBreathFrameMs = 0;


// These prevent the same radar frame from being processed many times.
uint32_t processedDistanceFrameMs = 0;
uint32_t processedHeartFrameMs = 0;
uint32_t processedBreathFrameMs = 0;


// ============================================================
//  6. STABLE ANALOG FILTER
// ============================================================
//
// This reusable filter is used for:
// - distance
// - heart rate
// - breathing rate
//
// It performs:
// 1. range check
// 2. jump rejection
// 3. confirmation delay
// 4. exponential moving average smoothing
// 5. timeout reset
// ============================================================

struct StableAnalogFilter {
  float minValue;
  float maxValue;
  float maxJump;
  float tauMs;

  uint32_t confirmMs;
  uint32_t timeoutMs;

  bool candidateActive;
  bool stable;
  bool lpfActive;

  float candidate;
  float value;

  uint32_t candidateSinceMs;
  uint32_t lastInputMs;
  uint32_t lpfLastMs;

  StableAnalogFilter(
    float minV,
    float maxV,
    float jump,
    float tau,
    uint32_t confirm,
    uint32_t timeout
  ) {
    minValue = minV;
    maxValue = maxV;
    maxJump = jump;
    tauMs = tau;
    confirmMs = confirm;
    timeoutMs = timeout;
    reset();
  }

  void reset() {
    candidateActive = false;
    stable = false;
    lpfActive = false;

    candidate = 0.0f;
    value = 0.0f;

    candidateSinceMs = 0;
    lastInputMs = 0;
    lpfLastMs = 0;
  }

  bool update(float x, uint32_t now) {
    // Step 1: reject impossible or invalid values.
    if (!isfinite(x) || x < minValue || x > maxValue) {
      return false;
    }

    lastInputMs = now;

    // Step 2: reject sudden jumps.
    // If the jump is too large, start a new candidate.
    if (!candidateActive || fabsf(x - candidate) > maxJump) {
      candidateActive = true;
      candidate = x;
      candidateSinceMs = now;

      stable = false;
      lpfActive = false;

      return false;
    }

    // Step 3: candidate tracking.
    // The candidate slowly follows small changes.
    candidate += 0.25f * (x - candidate);

    // Step 4: confirmation delay.
    // The value must remain stable long enough before being trusted.
    if (now - candidateSinceMs < confirmMs) {
      return false;
    }

    stable = true;

    // Step 5: exponential moving average.
    //
    // Formula:
    // y_k = y_(k-1) + alpha * (x_k - y_(k-1))
    //
    // where:
    // alpha = dt / (tau + dt)
    //
    // This makes the filter time-aware.
    if (!lpfActive) {
      value = x;
      lpfActive = true;
      lpfLastMs = now;
    } else {
      uint32_t dt = now - lpfLastMs;
      lpfLastMs = now;

      float alpha = (float)dt / (tauMs + (float)dt);
      value += alpha * (x - value);
    }

    return true;
  }

  void expire(uint32_t now) {
    if (lastInputMs == 0) return;

    // If no valid input arrived for too long, reset the filter.
    if (now - lastInputMs > timeoutMs) {
      reset();
    }
  }

  bool isStable() const {
    return stable && lpfActive;
  }

  float get() const {
    return value;
  }
};


// ============================================================
//  7. PRESENCE DEBOUNCE FILTER
// ============================================================
//
// This filter prevents one short false detection from being accepted.
// Presence must remain true for PRESENCE_CONFIRM_MS.
// Absence must remain true for ABSENCE_CONFIRM_MS.
// ============================================================

struct DebouncedPresence {
  bool stablePresent;
  bool candidateActive;

  uint32_t candidateSinceMs;
  uint32_t lastEvidenceMs;

  DebouncedPresence() {
    stablePresent = false;
    candidateActive = false;
    candidateSinceMs = 0;
    lastEvidenceMs = 0;
  }

  void update(bool evidence, uint32_t now) {
    if (evidence) {
      lastEvidenceMs = now;

      if (!candidateActive) {
        candidateActive = true;
        candidateSinceMs = now;
      }

      if (!stablePresent && now - candidateSinceMs >= PRESENCE_CONFIRM_MS) {
        stablePresent = true;
      }
    } else {
      if (!stablePresent) {
        candidateActive = false;
        candidateSinceMs = 0;
      }

      if (stablePresent && now - lastEvidenceMs >= ABSENCE_CONFIRM_MS) {
        stablePresent = false;
        candidateActive = false;
        candidateSinceMs = 0;
      }
    }
  }

  bool warmingUp() const {
    return candidateActive && !stablePresent;
  }
};


// ============================================================
//  8. ROBUST FINAL WINDOW ESTIMATOR
// ============================================================
//
// This is used to calculate one final value after one stable minute.
// It uses:
// 1. median
// 2. MAD: median absolute deviation
// 3. outlier rejection
// 4. mean of accepted samples
// ============================================================

struct RobustWindowEstimator {
  float samples[ESTIMATE_MAX_SAMPLES];

  int count;
  uint32_t firstSampleMs;
  uint32_t lastSampleMs;

  RobustWindowEstimator() {
    reset();
  }

  void reset() {
    count = 0;
    firstSampleMs = 0;
    lastSampleMs = 0;
  }

  void add(float x, uint32_t now) {
    if (!isfinite(x)) return;

    if (count == 0) {
      firstSampleMs = now;
    }

    if (count < ESTIMATE_MAX_SAMPLES) {
      samples[count] = x;
      count++;
      lastSampleMs = now;
    }
  }

  bool ready(uint32_t now) const {
    return count >= ESTIMATE_MIN_SAMPLES &&
           firstSampleMs > 0 &&
           now - firstSampleMs >= ESTIMATE_WINDOW_MS;
  }

  void sortArray(float *arr, int n) {
    for (int i = 1; i < n; i++) {
      float key = arr[i];
      int j = i - 1;

      while (j >= 0 && arr[j] > key) {
        arr[j + 1] = arr[j];
        j--;
      }

      arr[j + 1] = key;
    }
  }

  float median(float *arr, int n) {
    sortArray(arr, n);

    if (n % 2 == 1) {
      return arr[n / 2];
    }

    return 0.5f * (arr[n / 2 - 1] + arr[n / 2]);
  }

  bool estimate(float &estimatedValue, float &robustSpread, int &usedSamples) {
    if (count < ESTIMATE_MIN_SAMPLES) {
      return false;
    }

    float sorted[ESTIMATE_MAX_SAMPLES];
    float deviations[ESTIMATE_MAX_SAMPLES];

    for (int i = 0; i < count; i++) {
      sorted[i] = samples[i];
    }

    float med = median(sorted, count);

    for (int i = 0; i < count; i++) {
      deviations[i] = fabsf(samples[i] - med);
    }

    float mad = median(deviations, count);

    // 1.4826 converts MAD to a standard-deviation-like robust spread.
    robustSpread = 1.4826f * mad;

    if (robustSpread < MIN_ROBUST_SIGMA) {
      robustSpread = MIN_ROBUST_SIGMA;
    }

    float threshold = ESTIMATE_OUTLIER_K * robustSpread;

    float sum = 0.0f;
    usedSamples = 0;

    for (int i = 0; i < count; i++) {
      if (fabsf(samples[i] - med) <= threshold) {
        sum += samples[i];
        usedSamples++;
      }
    }

    if (usedSamples < ESTIMATE_MIN_SAMPLES / 2) {
      return false;
    }

    estimatedValue = sum / usedSamples;
    return true;
  }
};


// ============================================================
//  9. CREATE FILTER OBJECTS
// ============================================================

DebouncedPresence presenceGate;

StableAnalogFilter distanceFilter(
  MIN_DISTANCE_CM,
  MAX_DISTANCE_CM,
  DISTANCE_MAX_JUMP_CM,
  DISTANCE_TAU_MS,
  DISTANCE_CONFIRM_MS,
  DISTANCE_TIMEOUT_MS
);

StableAnalogFilter heartFilter(
  MIN_HEART_BPM,
  MAX_HEART_BPM,
  HEART_MAX_JUMP_BPM,
  HEART_TAU_MS,
  HEART_CONFIRM_MS,
  HEART_TIMEOUT_MS
);

StableAnalogFilter breathFilter(
  MIN_BREATH_RATE,
  MAX_BREATH_RATE,
  BREATH_MAX_JUMP,
  BREATH_TAU_MS,
  BREATH_CONFIRM_MS,
  BREATH_TIMEOUT_MS
);

RobustWindowEstimator heartFinalEstimator;
RobustWindowEstimator breathFinalEstimator;

bool finalEstimatePrinted = false;
uint32_t lastEstimateSampleMs = 0;


// ============================================================
//  10. BASIC BYTE DECODING HELPERS
// ============================================================

uint8_t checksum(const uint8_t *data, size_t len) {
  uint8_t ret = 0;

  for (size_t i = 0; i < len; i++) {
    ret ^= data[i];
  }

  return ~ret;
}

uint16_t readBE16(const uint8_t *p) {
  return ((uint16_t)p[0] << 8) | p[1];
}

uint32_t readLE32(const uint8_t *p) {
  return ((uint32_t)p[0]) |
         ((uint32_t)p[1] << 8) |
         ((uint32_t)p[2] << 16) |
         ((uint32_t)p[3] << 24);
}

float readFloatLE(const uint8_t *p) {
  uint32_t raw = readLE32(p);

  float value;
  memcpy(&value, &raw, sizeof(value));

  return value;
}


// ============================================================
//  11. OPTIONAL RADAR RESET
// ============================================================

void resetRadarIfConnected() {
  if (RADAR_RST_PIN < 0) return;

  pinMode(RADAR_RST_PIN, OUTPUT);

  digitalWrite(RADAR_RST_PIN, LOW);
  delay(100);

  digitalWrite(RADAR_RST_PIN, HIGH);
  delay(1000);
}


// ============================================================
//  12. HANDLE COMPLETE RADAR FRAMES
// ============================================================
//
// This function receives valid decoded radar frames.
// It only stores raw values.
// Filtering is done later in updateFilteredOutput().
// ============================================================

void handleFrame(uint16_t type, const uint8_t *data, uint16_t len) {
  uint32_t now = millis();

  lastValidFrameMs = now;

  switch (type) {
    case 0x0A13: { // total phase, breath phase, heart phase
      if (len >= 12) {
        float totalPhase  = readFloatLE(data + 0);
        float breathPhase = readFloatLE(data + 4);
        float heartPhase  = readFloatLE(data + 8);

        if (PRINT_PHASES) {
          Serial.print("Phase | total: ");
          Serial.print(totalPhase, 3);

          Serial.print(" | breath: ");
          Serial.print(breathPhase, 3);

          Serial.print(" | heart: ");
          Serial.println(heartPhase, 3);
        }
      }
      break;
    }

    case 0x0A14: { // breathing rate
      if (len >= 4) {
        rawBreathRate = readFloatLE(data);
        lastBreathFrameMs = now;

        if (PRINT_RAW) {
          Serial.print("RAW breath rate: ");
          Serial.println(rawBreathRate, 2);
        }
      }
      break;
    }

    case 0x0A15: { // heart rate
      if (len >= 4) {
        rawHeartBpm = readFloatLE(data);
        lastHeartFrameMs = now;

        if (PRINT_RAW) {
          Serial.print("RAW heart rate: ");
          Serial.println(rawHeartBpm, 2);
        }
      }
      break;
    }

    case 0x0A16: { // detection distance
      if (len >= 8) {
        uint32_t flag = readLE32(data);
        float distance = readFloatLE(data + 4);

        rawDistanceValid = (flag == 1);
        rawDistanceCm = distance;
        lastDistanceFrameMs = now;

        if (PRINT_RAW) {
          Serial.print("RAW distance: ");

          if (rawDistanceValid) {
            Serial.print(rawDistanceCm, 2);
            Serial.println(" cm");
          } else {
            Serial.println("no valid target");
          }
        }
      }
      break;
    }

    case 0x0F09: { // human detected, available on newer firmware
      if (len >= 1) {
        rawHumanDetected = data[0] ? true : false;
        lastHumanFrameMs = now;

        if (PRINT_RAW) {
          Serial.print("RAW human detected: ");
          Serial.println(rawHumanDetected ? "YES" : "NO");
        }
      }
      break;
    }

    default:
      // Unknown frame type. Keep silent during normal use.
      // Uncomment for debugging:
      // Serial.print("Unknown frame type: 0x");
      // Serial.println(type, HEX);
      break;
  }
}


// ============================================================
//  13. BYTE-BY-BYTE RADAR FRAME PARSER
// ============================================================
//
// UART data arrives as a stream of bytes.
// This state machine rebuilds valid radar frames.
// ============================================================

void parseRadarByte(uint8_t b) {
  switch (state) {
    case WAIT_SOF:
      if (b == SOF) {
        headerBuf[0] = b;
        headerIndex = 1;
        state = READ_HEADER;
      }
      break;

    case READ_HEADER:
      headerBuf[headerIndex] = b;
      headerIndex++;

      if (headerIndex >= HEADER_LEN) {
        uint8_t expectedHeaderChecksum = checksum(headerBuf, 7);

        if (expectedHeaderChecksum != headerBuf[7]) {
          state = WAIT_SOF;
          return;
        }

        dataLen = readBE16(headerBuf + 3);
        frameType = readBE16(headerBuf + 5);

        if (dataLen > MAX_DATA_LEN) {
          state = WAIT_SOF;
          return;
        }

        dataIndex = 0;
        state = READ_DATA_AND_CHECKSUM;
      }
      break;

    case READ_DATA_AND_CHECKSUM:
      if (dataIndex < dataLen) {
        dataBuf[dataIndex] = b;
        dataIndex++;
      } else {
        uint8_t receivedDataChecksum = b;
        uint8_t expectedDataChecksum = checksum(dataBuf, dataLen);

        if (receivedDataChecksum == expectedDataChecksum) {
          handleFrame(frameType, dataBuf, dataLen);
        }

        state = WAIT_SOF;
      }
      break;
  }
}


// ============================================================
//  14. FINAL ONE-MINUTE ESTIMATE
// ============================================================
//
// This function collects stable filtered values for one minute.
// Then it calculates one robust estimate using median + MAD.
// ============================================================

void updateFinalEstimate(uint32_t now) {
  // Only collect samples if both vitals are already stable.
  if (!heartFilter.isStable() || !breathFilter.isStable()) {
    heartFinalEstimator.reset();
    breathFinalEstimator.reset();

    finalEstimatePrinted = false;
    lastEstimateSampleMs = 0;

    return;
  }

  // After one final estimate has been printed, stop until the target is lost.
  if (finalEstimatePrinted) {
    return;
  }

  // Collect one filtered sample per second.
  if (now - lastEstimateSampleMs >= ESTIMATE_SAMPLE_EVERY_MS) {
    lastEstimateSampleMs = now;

    float calibratedHeart = heartFilter.get() + HEART_CALIBRATION_OFFSET_BPM;
    float calibratedBreath = breathFilter.get() + BREATH_CALIBRATION_OFFSET;

    heartFinalEstimator.add(calibratedHeart, now);
    breathFinalEstimator.add(calibratedBreath, now);
  }

  // Wait until both windows are ready.
  if (!heartFinalEstimator.ready(now) || !breathFinalEstimator.ready(now)) {
    return;
  }

  float estimatedHeart = 0.0f;
  float estimatedBreath = 0.0f;

  float heartSpread = 0.0f;
  float breathSpread = 0.0f;

  int usedHeartSamples = 0;
  int usedBreathSamples = 0;

  bool heartOk = heartFinalEstimator.estimate(
    estimatedHeart,
    heartSpread,
    usedHeartSamples
  );

  bool breathOk = breathFinalEstimator.estimate(
    estimatedBreath,
    breathSpread,
    usedBreathSamples
  );

  if (heartOk && breathOk) {
    Serial.println();
    Serial.println("========== FINAL STABLE ESTIMATE ==========");

    Serial.print("Estimated heart rate: ");
    Serial.print(estimatedHeart, 1);
    Serial.print(" bpm");
    Serial.print(" | robust spread: ±");
    Serial.print(heartSpread, 1);
    Serial.print(" | samples used: ");
    Serial.println(usedHeartSamples);

    Serial.print("Estimated breath rate: ");
    Serial.print(estimatedBreath, 1);
    Serial.print(" breaths/min");
    Serial.print(" | robust spread: ±");
    Serial.print(breathSpread, 1);
    Serial.print(" | samples used: ");
    Serial.println(usedBreathSamples);

    Serial.println("===========================================");
    Serial.println();

    finalEstimatePrinted = true;
  }
}


// ============================================================
//  15. MAIN FILTERING ARCHITECTURE
// ============================================================
//
// This is the central decision layer.
// It converts raw radar values into trusted filtered output.
// ============================================================
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
void loop() {
  while (RADAR_SERIAL.available() > 0) {
  parseRadarByte((uint8_t)RADAR_SERIAL.read());
}
  
while (RADAR_SERIAL.available() > 0) {
  parseRadarByte((uint8_t)RADAR_SERIAL.read());
}
  updateFilteredOutput();

  static uint32_t lastWarningMs = 0;

  if (
    millis() > 5000 &&
    lastValidFrameMs == 0 &&
    millis() - lastWarningMs > 3000
  ) {
    lastWarningMs = millis();

    Serial.println(
      "No valid radar frames yet. Check GND, TX/RX crossing, radar power, and baud rate."
    );
  }
}

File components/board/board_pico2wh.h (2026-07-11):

#ifndef BOARD_PICO2WH_H
#define BOARD_PICO2WH_H

/* Authoritative pin map for the Pico 2 WH sensor-module PCB.
 * PCB layout owns this file in spirit — do not hardcode GPIO numbers elsewhere.
 *
 * Updated 2026-06-03 to match the hardware actually wired for the v1 PoC.
 * The previous placeholder values are gone; if anything here is wrong, fix
 * here, not at the call site.
 */

#include "hardware/i2c.h"
#include "hardware/uart.h"

/* ── I²C0 — BMP280 + ENS160 + SH1122 OLED ───────────────────────────────── */
#define BOARD_I2C_INST          i2c0
#define BOARD_I2C_SDA_PIN       8     /* GP8, pin 11 */
#define BOARD_I2C_SCL_PIN       9     /* GP9, pin 12 */
/* I²C bus speed. Default 400 kHz fast-mode; can be overridden at build time
 * with -DBOARD_I2C_FREQ_HZ=100000U for a diagnostic slow-mode build that
 * tolerates marginal pull-ups (e.g. after removing a sensor breakout that
 * carried onboard pull-up resistors). */
#ifndef BOARD_I2C_FREQ_HZ
#define BOARD_I2C_FREQ_HZ       400000U
#endif

#define BOARD_BMP280_ADDR       0x76U   /* SDO low; 0x77 if SDO high */
#define BOARD_AHT21_ADDR        0x38U   /* AHT21 has a fixed I²C address */
#define BOARD_ENS160_ADDR       0x53U   /* default; 0x52 if ADDR pin pulled low */
#define BOARD_OLED_ADDR         0x3CU   /* SA0 low; 0x3D if SA0 high */
#define BOARD_BH1750_ADDR       0x23U   /* default; 0x5C if ADDR pin pulled high */

/* ── UART1 — mmWave radar (shared UART for the MR60BHA2 OR the 24 GHz HMMD
 *           module; selection via /cfg/sensors.json per §3.2 / §7.4 /
 *           ADR-0007 — the HMMD variant reuses this UART, no new pins) ──── */
/* GP4/GP5 are UART1 on RP2350. The hardware perspective: MCU TX = GP5,
 * MCU RX = GP4. */
#define BOARD_RADAR_UART_INST   uart1
#define BOARD_RADAR_TX_PIN      5     /* GP5, pin 7 — MCU TX → radar RX */
#define BOARD_RADAR_RX_PIN      4     /* GP4, pin 6 — MCU RX ← radar TX */
#define BOARD_RADAR_BAUD        115200U

/* ── Radar — discrete GPIO indicators (in addition to UART data) ─────────── */
/* MR60BHA2 (HMMD) exposes a presence signal on a discrete GPIO line and an
 * RGB-LED indicator pin. The C1001 exposes presence + fall-detection on
 * two separate GPIO lines. None of these are strictly needed for sensor
 * sampling (the UART carries the full payload) but they're useful for
 * fast presence-edge detection and as bring-up sanity checks. */
#define BOARD_MR60BHA2_PRESENCE_PIN  2   /* GP2, pin 4  — HMMD presence */
#define BOARD_MR60BHA2_LED_PIN       3   /* GP3, pin 5  — onboard RGB LED */
#define BOARD_C1001_PRESENCE_PIN     6   /* GP6, pin 9  */
#define BOARD_C1001_FALL_PIN         7   /* GP7, pin 10 — fall detection */

/* ── GPIO — buttons ──────────────────────────────────────────────────────── */
/* v1 PoC: one user button (display-cycle), plus the on-board RUN pin for reset. */
#define BOARD_BTN_DISPLAY_PIN   16    /* GP16, pin 21 — active-low, internal pull-up */

/* ── GPIO — LEDs ──────────────────────────────────────────────────────────── */
/* CYW43 onboard LED is driven via pico_cyw43_arch (not a bare GPIO). */
/* POWER/WIFI swapped 2026-06-22 to match the as-built PCB (LEDs were wired to
 * the opposite pins vs the original assignment). */
#define BOARD_LED_POWER_PIN     15    /* GP15, pin 20 — "system on" indicator */
#define BOARD_LED_WIFI_PIN      14    /* GP14, pin 19 — "wifi associated" indicator */

/* ── ADC0 — GL5516 LDR (generic module variant only; advanced module leaves
 *           this pin unpopulated, BH1750 over I²C handles light there) ──── */
/* GP26 = ADC channel 0 on RP2350. Wired as:
 *   3V3 ── R6 (LDR, GL5516) ── ADC_NODE ── R7 (1 kΩ to GND) ── GND
 *                              │
 *                              └─ GP26 / ADC0 / pin 31
 * So the ADC sees:  V = VCC × R_fixed / (R_LDR + R_fixed). See ADR-0001. */
#define BOARD_LDR_ADC_INPUT     0     /* hardware_adc input index (= ADC0)  */
#define BOARD_LDR_ADC_GPIO      26    /* GP26, pin 31                       */
#define BOARD_LDR_VCC_V         3.3f
#define BOARD_LDR_FIXED_OHM     1000.0f  /* R7 in the divider                */

/* ── Generic / reserved GPIO labels ──────────────────────────────────────── */
/* The PCB exposes D0, D2, D8, D9, D10 as generic breakouts; not bound to a
 * sensor in v1. Listed here for traceability against the schematic. */
#define BOARD_GPIO_D0           1     /* pin 2  */
#define BOARD_GPIO_D2           13    /* pin 17 */
#define BOARD_GPIO_D8           10    /* pin 14 */
#define BOARD_GPIO_D9           11    /* pin 15 */
#define BOARD_GPIO_D10          12    /* pin 16 */

/* ── USB ──────────────────────────────────────────────────────────────────── */
/* TinyUSB owns the USB peripheral. No GPIO pin constants needed here;
 * CDC0 = data, CDC1 = logs (see CLAUDE.md §8.1). */
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

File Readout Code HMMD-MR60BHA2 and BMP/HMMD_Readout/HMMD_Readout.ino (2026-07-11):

/*
  Waveshare HMMD mmWave Sensor + Raspberry Pi Pico 2W
  Arduino IDE

  Wiring:
    HMMD 3V3 -> Pico 3V3
    HMMD GND -> Pico GND
    HMMD TX  -> Pico GP5
    HMMD RX  -> Pico GP4
    HMMD OT2 -> Pico GP15

  Output:
    Pico GP16 -> wake/start input of another 3.3V system

  Detection condition:
    Person must be detected between 90 cm and 150 cm.
    Energy gate 0 is ignored completely.
    Distance is smoothed using EMA.
*/

#define RADAR_RX_PIN 5
#define RADAR_TX_PIN 4
#define OT2_PIN      15
#define WAKE_OUT_PIN 16

#define RadarSerial Serial2

// Main accepted distance window
const uint16_t ENTER_MIN_CM = 90;
const uint16_t ENTER_MAX_CM = 150;

// Hysteresis window.
// Once active, it stays active while still roughly inside this wider range.
const uint16_t EXIT_MIN_CM = 80;
const uint16_t EXIT_MAX_CM = 170;

// Basic sanity limits
const uint16_t ABSOLUTE_MIN_CM = 30;
const uint16_t ABSOLUTE_MAX_CM = 300;

// EMA smoothing.
// Lower = smoother but slower.
// Higher = faster but more jumpy.
const float EMA_ALPHA = 0.25;

// Reject sudden unrealistic jumps
const uint16_t MAX_DISTANCE_JUMP_CM = 50;

// 3 frames = about 300 ms confirmation
const uint8_t REQUIRED_HITS = 3;

// 6 frames = about 600 ms before switching off
const uint8_t REQUIRED_MISSES = 6;

bool emaReady = false;
float emaDistanceCm = 0;
uint16_t lastAcceptedDistanceCm = 0;

bool personInWindow = false;
uint8_t hitCount = 0;
uint8_t missCount = 0;

unsigned long lastPrintMs = 0;

// Command: set HMMD to report mode
const uint8_t CMD_REPORT_MODE[] = {
  0xFD, 0xFC, 0xFB, 0xFA,
  0x08, 0x00,
  0x12, 0x00,
  0x00, 0x00,
  0x04, 0x00, 0x00, 0x00,
  0x04, 0x03, 0x02, 0x01
};

const uint8_t REPORT_HEADER[4] = {0xF4, 0xF3, 0xF2, 0xF1};
const uint8_t REPORT_TAIL[4]   = {0xF8, 0xF7, 0xF6, 0xF5};

uint8_t frame[96];
uint16_t framePos = 0;
uint16_t expectedFrameLen = 0;

// Function declarations
void processByte(uint8_t b);
bool validTail();
void parseReportFrame();
int findStrongestGateIgnoringGate0(uint16_t energies[16]);
bool updateEmaDistance(uint16_t newDistanceCm);
void resetEmaDistance();
void updateDecision(
  uint8_t radarDetected,
  bool ot2High,
  bool validDistance,
  bool usefulGate,
  uint16_t filteredDistanceCm
);
void printDebug(
  uint8_t radarDetected,
  bool ot2High,
  uint16_t rawDistanceCm,
  uint16_t filteredDistanceCm,
  int strongestGate,
  uint16_t energies[16]
);
void resetFrame();

void setup() {
  Serial.begin(115200);
  delay(1500);

  Serial.println();
  Serial.println("HMMD 90-150cm EMA detector starting...");

  pinMode(OT2_PIN, INPUT);
  pinMode(WAKE_OUT_PIN, OUTPUT);
  digitalWrite(WAKE_OUT_PIN, LOW);

  RadarSerial.setRX(RADAR_RX_PIN);
  RadarSerial.setTX(RADAR_TX_PIN);
  RadarSerial.setFIFOSize(256);
  RadarSerial.begin(115200);

  delay(500);

  Serial.println("Switching HMMD to report mode...");
  RadarSerial.write(CMD_REPORT_MODE, sizeof(CMD_REPORT_MODE));

  Serial.println("Ready.");
}

void loop() {
  while (RadarSerial.available()) {
    uint8_t b = RadarSerial.read();
    processByte(b);
  }
}

void processByte(uint8_t b) {
  // Find report header: F4 F3 F2 F1
  if (framePos < 4) {
    if (b == REPORT_HEADER[framePos]) {
      frame[framePos++] = b;
    } else {
      framePos = (b == REPORT_HEADER[0]) ? 1 : 0;
      if (framePos == 1) {
        frame[0] = b;
      }
    }
    return;
  }

  if (framePos >= sizeof(frame)) {
    resetFrame();
    return;
  }

  frame[framePos++] = b;

  // After header + length bytes
  if (framePos == 6) {
    uint16_t payloadLen = frame[4] | (frame[5] << 8);
    expectedFrameLen = 4 + 2 + payloadLen + 4;

    if (expectedFrameLen > sizeof(frame) || payloadLen < 35) {
      resetFrame();
      return;
    }
  }

  if (expectedFrameLen > 0 && framePos >= expectedFrameLen) {
    if (validTail()) {
      parseReportFrame();
    }
    resetFrame();
  }
}

bool validTail() {
  return frame[expectedFrameLen - 4] == REPORT_TAIL[0] &&
         frame[expectedFrameLen - 3] == REPORT_TAIL[1] &&
         frame[expectedFrameLen - 2] == REPORT_TAIL[2] &&
         frame[expectedFrameLen - 1] == REPORT_TAIL[3];
}

void parseReportFrame() {
  uint16_t payloadLen = frame[4] | (frame[5] << 8);
  if (payloadLen < 35) {
    return;
  }

  uint8_t radarDetected = frame[6];
  uint16_t rawDistanceCm = frame[7] | (frame[8] << 8);

  uint16_t energies[16];

  for (int i = 0; i < 16; i++) {
    energies[i] = frame[9 + i * 2] | (frame[10 + i * 2] << 8);
  }

  bool ot2High = digitalRead(OT2_PIN) == HIGH;

  // Find strongest gate, but ignore gate 0 completely.
  int strongestGate = findStrongestGateIgnoringGate0(energies);

  // For 90-150 cm, the useful gates are:
  // gate 1: about 70-140 cm
  // gate 2: about 140-210 cm
  bool usefulGate = strongestGate == 1 || strongestGate == 2;

  bool validDistance =
    rawDistanceCm >= ABSOLUTE_MIN_CM &&
    rawDistanceCm <= ABSOLUTE_MAX_CM;

  uint16_t filteredDistanceCm = 0;

  if (radarDetected == 1 && ot2High && validDistance && usefulGate) {
    bool accepted = updateEmaDistance(rawDistanceCm);

    if (accepted) {
      filteredDistanceCm = (uint16_t)(emaDistanceCm + 0.5);
    } else {
      filteredDistanceCm = 0;
    }
  } else {
    resetEmaDistance();
  }

  updateDecision(
    radarDetected,
    ot2High,
    validDistance,
    usefulGate,
    filteredDistanceCm
  );

  printDebug(
    radarDetected,
    ot2High,
    rawDistanceCm,
    filteredDistanceCm,
    strongestGate,
    energies
  );
}

int findStrongestGateIgnoringGate0(uint16_t energies[16]) {
  int strongestGate = 1;
  uint16_t strongestEnergy = energies[1];

  // Start from 1, not 0.
  // Gate 0 is ignored because it is noisy.
  for (int i = 2; i < 16; i++) {
    if (energies[i] > strongestEnergy) {
      strongestEnergy = energies[i];
      strongestGate = i;
    }
  }

  return strongestGate;
}
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

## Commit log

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2026-05-21 Add new firmware project: Pico 2 WH C11/FreeRTOS sensor module
    Complete firmware scaffold for the RMMS Advanced Sensor Module, replacing
    the previous MicroPython/ESP32 implementation. Key properties:
    - MCU: Raspberry Pi Pico 2 WH (RP2350, dual Cortex-M33, CYW43 Wi-Fi)
    - Language: C11 with FreeRTOS SMP (both cores), lwIP, mbedTLS, TinyUSB
    - Transport: mTLS (ECDSA P-256) over USB-CDC (primary) and Wi-Fi (failover)
    - Wire format: JSON (RFC 8259) via snprintf encoders, jsmn tokenizer
    - Storage: littlefs over QSPI flash; all config/state files in JSON
    - Identity: static factory-provisioned certs; no registration protocol
    - Sensors: BME280 (env), Seeed MR60BHA2 + DFRobot C1001 (radar), GL5516 (li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
    [app_config.h, app_main.c, board_pico2wh.h]
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2026-06-03 Add DEMO.md — supervisor demo runbook
    Step-by-step session script for the 12:15 demo, scoped to the actual
    hardware available (Pico + USB only, no jumpers for sensor wiring).
    Mobile hotspot path; includes the cert re-issuance + firmware rebuild
    needed each session because the hotspot reassigns the tablet's IP
    (broker cert SAN must match).
    Sections:
    - §0 setup (~15 min before demo): provision_ca.sh, scp, Mosquitto restart,
    rebuild firmware with current IP, flash, verify.
    - §1 demo flow (~12 min): architecture, live publish, provisioning script,
    Yasmina's MagicMirror² UI, bring-up ladder, anticipated questions.
    - Plan B for if Wi-Fi breaks at demo time (laptop ↔ tablet mTLS on /cmd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
2026-06-04 Add ENS160 + SH1122 drivers; per-sensor bring-up programs; updated pin map
    Three sensors confirmed end-to-end on hardware this session:
    - BME280 (existing driver) — temp/hum/pressure via I²C0
    - ENS160 (new driver) — eCO2/TVOC/AQI via I²C0, warmup-state-aware
    - SH1122 256x64 4bpp grayscale OLED (new driver) — four-page cycled status UI
    with live BME280 + ENS160 readouts, including ENS160 initial-startup
    signaling (~1 h burn-in on a new sensor)
    MR60BHA2 radar bring-up is built and staged but the hardware wasn't
    available this afternoon — awaits next session.
    - components/sensor_air/ (new) — ENS160 driver matching the existing
    sensor_env shape; init verifies part ID 0x0160,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
    [board_pico2wh.h, ens160.c]
2026-06-04 bringup_sensors: drive the SH1122 OLED alongside the live MQTT publishes
    Single UF2 that does everything proven this session: read BME280 + ENS160 on
    I²C0, publish env + air over mTLS+MQTT, AND render four status pages on the
    SH1122 OLED:
    1. NETWORK + BROKER — Wi-Fi IP, broker IP:port, MQTT OK/--, uptime
    2. ENV /env — live T/H/P + cumulative publish counter
    3. AIR /air — AQI/CO2/TVOC (with warmup-state overlay) + publish counter
    4. BUILD INFO — board, firmware identity
    Confirmed on hardware earlier this session. OLED render runs in a separate
    priority-1 task pinned to core 0 (sensor + MQTT publishes at priority 2 keep
    preempting); shadow state is updated by the publish func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
2026-06-05 mirror: wire MMM-CustomMQTTBridge to the firmware over mTLS
    The bridge now opens an mqtts:// connection to the RMMS broker (mirror cert
    from scripts/provision_ca.sh), subscribes to rmms/+/+, parses the firmware's
    §9.2 JSON envelope, and re-broadcasts each field as the sensors/<name>
    notification that MMM-SensorUI already consumes. MMM-SensorUI itself is not
    touched — Yasmina's parallel UI work stays intact, the bridge does all the
    rmms/...→sensors/... translation in node_helper.
    Mapping (per CLAUDE.md §9.5):
    rmms/<uuid>/env → sensors/temperature, sensors/humidity
    rmms/<uuid>/air → sensors/airquality (UBA label), sensors/co2, sensors/tvoc
    rmms/<uuid>/radar → sensors/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
2026-06-05 spec: document the bridge's rmms/...→sensors/... namespace adapter (§9.5.1)
    The mirror uses two distinct namespaces by design:
    - rmms/<uuid>/... = broker MQTT wire contract (§9.1, §9.2)
    - sensors/<field> = mirror-internal notification bus
    MMM-CustomMQTTBridge is the adapter between them. Yasmina's MMM-SensorUI
    consumes sensors/* events without knowing anything about wire JSON or
    quality flags. Until now this dual-namespace was implicit — the bridge's
    translation read as a hack rather than the intentional separation of
    concerns it actually is.
    This commit makes it explicit:
    - CLAUDE.md §9.5.1 documents the dual-namespace contract and points at
    the bridge's node_helper as the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
2026-06-05 provision: USB-serial bringup that writes the device bundle into littlefs
    Replaces the bake_certs.py compile-time path. Flash bringup_provision.uf2,
    run scripts/provision_device.py against an out/device-<uuid>/ bundle, and
    the device lands the CA + ECDSA cert chain + per-device JSON config into
    the §11 canonical paths. SHA-256 reported per file and re-verified via
    LIST before the watchdog reboot.
    Path whitelist (/cfg/ /certs/ /state/) is enforced on-device so a
    misbehaving host can't write outside the documented layout. Host script
    tolerates identity-only bundles (wifi/broker/sensors optional), matching
    how provision_ca.sh mints only the identity half.
    Verified end-to-end on hardware: all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
2026-06-05 bringups: read identity + config from littlefs, drop compile-time bake
    Identity (UUID + ECDSA cert chain) and per-deployment config (Wi-Fi
    creds, broker address, radar choice) now load from littlefs at boot via
    new identity_load() + cfg_load_{wifi,broker,sensors}() calls. The
    bringup_provision flow that lands those files is the only producer;
    bringup_mqtt and bringup_sensors are now pure consumers.
    This kills the bake_certs.py path entirely:
    - No more CERTS_DIR cmake gate.
    - No more WIFI_SSID / WIFI_PSK / BROKER_IP / BROKER_PORT target
    compile_definitions.
    - bake_certs.py deleted; bake-time secrets cannot leak into a UF2
    artefact any more, full stop.
    Supporting changes:
    - s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
2026-06-05 radar: pin reader task to core 0, yield with vTaskDelay in read_byte
    Embedding the radar reader task into bringup_sensors revealed two
    SMP-related issues that didn't show up in the standalone bringup_radar:
    1. taskYIELD() in read_byte is a no-op when the reader is the
    highest-priority task on its core — the task spin-saturates the
    core. Combined with pico_cyw43_arch_lwip_threadsafe_background
    (which is documented as not FreeRTOS-SMP-aware), this starved the
    alarm-pool path and froze MQTT after the first 1 Hz tick.
    2. Pinning the reader to core 1 made the starvation worse, not
    better — same root cause, different core.
    Fix:
    - read_byte() now uses vTaskDela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
    [radar_bha2.c]
2026-06-05 demo: one-command laptop bring-up + updated runbook
    scripts/demo_start.sh wraps every laptop-side step into a single
    invocation: refresh_broker.sh against today's tablet IP, sed the
    bridge URL in MagicMirror/config/config.js, rewrite broker.json in
    the latest device bundle, copy the bundle + provision_device.py to
    the Windows-visible path, kill anything on :8080, relaunch MM² in
    the background logging to /tmp/mm2.log.
    DEMO.md §0 rewritten around that script. Manual checklist is now:
    - flash bringup_provision.uf2 (one BOOTSEL drag)
    - py -3.13 provision_device.py COM<N> device-<uuid>
    - flash bringup_sensors.uf2
    - open http://localhost:8080
    Adds a small troubleshooting table for the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
2026-06-05 broker: resolve hostname via lwIP DNS when ip field is empty
    bringup_sensors used to require broker.json to carry a literal IP and
    hard-block if it didn't. Now: try the ip field first (fast path, no
    network round-trip), fall back to dns_gethostbyname() on the host
    field with a 5 s timeout. Resolution result is logged so it's obvious
    which path was taken.
    This is plain unicast DNS (the LWIP_DNS module). It does NOT resolve
    *.local mDNS names — that needs a separate lwIP query module which is
    intentionally deferred. For hotspot networks (no DNS), the existing
    demo_start.sh writes the literal tablet IP into broker.json each
    session, so the IP-literal path still covers that case.
    DNS callbac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
2026-06-07 sensor_light: vtable + GL5516 driver; SW2 page toggle + WiFi LED; ADR-0001 rewrite
    ADR-0001 was wrong: the GL5516 is not "dropped from the PCB" by the
    BH1750. The PCB intentionally supports both populations because the
    project ships in two product variants:
    Advanced module (this demo): MR60BHA2 radar + BH1750 on its breakout
    + MagicMirror² UI.
    Generic module (compat-only): HMMD presence + GL5516 LDR + raw MQTT,
    for rooms without a mirror.
    Both light sensors exist to better map Activities of Daily Living
    (ADL) — recording when room lights turn on/off as a behavioural proxy
    for activity patterns. ADR rewritten to capture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
    [bh1750.c, board_pico2wh.h, gl5516.c]
2026-06-07 sensors: I²C mutex, AHT21 + ENS160 robustness, slow-clock build
    Hardware bring-up of the AHT21+ENS160 combo (after pulling the BME280)
    surfaced four orthogonal issues; each fix lives in this commit.
    I²C bus contention. render_task (OLED) and sensors_task (AHT21 /
    ENS160 / BH1750) were both calling pico-sdk i2c_*_blocking on the same
    i2c0 instance with no synchronisation. Two transactions on the bus at
    once interleave at the byte level, which manifested as: AHT21 humidity
    stuck on a previous value (e.g. 89.05 %) over many samples while
    temperature still updated; BH1750 reading 0 lux; ENS160 reading all
    zeros; OLED reporting `I2C data row failed: -1`. Added a single
    FreeRTOSsemaphore (g_i2c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
    [aht21.c, board_pico2wh.h, ens160.c]
2026-06-07 bh1750: switch to one-shot mode, re-power-on each read
    Continuous H-resolution mode is fragile on a shared I²C bus: once the
    chip latched into power-down (after a glitch from an earlier bus
    collision) it stayed there across resets, returning 0 lux forever
    regardless of actual ambient light.
    One-shot H-resolution is self-recovering — every read sends POWER_ON +
    ONESHOT_H, waits the 180 ms conversion window, and the chip auto-powers
    down after the burst read. No state to keep good between cycles.
    Verified on hardware: ambient ~0.8 lux in a dim room, ~2000+ lux with
    a phone flashlight pointed at the BH1750 on the MR60BHA2 breakout.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
    [bh1750.c]
2026-06-08 demo_start: target the fixed demo device, not the newest bundle
    refresh_broker.sh (called in step 1) runs provision_ca.sh, which mints
    a brand-new random-UUID device bundle every invocation. The old
    `ls -dt out/device-* | head -1` therefore always grabbed that throwaway
    and wrote the updated broker.json into it — while the bench Pico is
    provisioned from a fixed device bundle whose broker.json was left
    stale. Result: the Pico kept connecting to the previous session's
    broker IP after a network change.
    Pin the demo device UUID (DEMO_UUID_DEFAULT, overridable as $2), update
    that bundle's broker.json, copy that bundle to the Windows path, and
    print its exact name in the checklist. Its certs ar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
2026-06-08 ens160: detect + recover when the chip drops out of STANDARD mode
    Field symptom: after running a while the air sample reads
    AQI=0 CO2=0 TVOC=0 with q=0 — which looked like NORMAL-but-zero, an
    impossible state for a working ENS160 (its eCO2 floor is 400 ppm).
    Root cause: STATUS read back 0x00. The validity bits (3:2) are then 00,
    which ens160_validity() reports as NORMAL — but bit 7 (STATAS, "an
    OPMODE is running") is also clear, meaning the chip has fallen out of
    STANDARD mode and isn't measuring at all (DATA_* registers read zero).
    The validity field is only meaningful while STATAS is set; reading it
    in isolation masked a stopped device as "normal".
    - ens160.h: STATAS/STATER/NE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
    [ens160.c]
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2026-06-08 firmware: fix integration drift so sensor_module builds on sys_freertos
    With the sys_freertos cyw43 hang resolved, the §7 production firmware
    (main/, task-per-producer over pico_cyw43_arch_lwip_sys_freertos) is
    worth building again. Two pieces of drift blocked it:
    - ui_input was written for two buttons (BOARD_BTN_A/B_PIN) but the v1
    PCB has one (SW2 = BOARD_BTN_DISPLAY_PIN, renamed during the SW2/LED
    work). Collapsed the driver + Button enum to the single display
    button; app_main's handler matches BTN_DISPLAY.
    - mbedtls_ms_time() (required by MBEDTLS_PLATFORM_MS_TIME_ALT) was only
    provided locally in each bring-up .c, so the firmware link failed.
    Moved it to tls_con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
    [app_main.c, ui_input.c]
2026-06-08 firmware(§7): complete production firmware on the proven Wi-Fi/mTLS/MQTT path
    Brings the §7 production firmware (main/) from a never-integrated skeleton to a
    building, task-decomposed firmware on the hardware-proven transport, after the
    decision to drop USB-CDC and use Wi-Fi as the sole v1 transport (ADR-0002).
    The skeleton had the right shape (tasks + queues + watchdog) but the logic was
    never wired: the queue-draining transport_task was missing, there was no
    air_task, the sensor tasks were hardcoded to the wrong parts (BME280/GL5516 vs
    the AHT21/BH1750 bench), the two TLS/MQTT stacks (custom stream_t vs proven
    lwIP-altcp) were never reconciled, EnvSample/LightSample were doubly-defined,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
    [air_task.c, app_config.h, app_main.c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]
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2026-06-08 firmware: on-screen Wi-Fi/MQTT bring-up diagnostic (OLED STATUS line)
    The USB-serial log console doesn't work under sys_freertos (pico_stdio_usb
    tud_task pump stalls), so add an OLED-based diagnostic instead: transport_task
    pushes its bring-up stage to a STATUS-page line via ui_oled_set_diag() —
    "cyw43 init.." / "assoc <ssid>.." / "WIFI FAIL rc=-N" / "tls cfg.." /
    "mqtt connect.." / "MQTT up" — with the actual rc on failure. Lets us see
    exactly where bring-up stops (and hang vs. error) with no working serial log.
    [transport_mqtt.c, ui_oled.c]
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2026-06-11 spool: non-volatile flash FIFO for loss-tolerant uplink + time-sync (ADR-0003)
    1 MB raw circular log below littlefs (flash_map.h tiles the regions); QoS-1
    retry-until-PUBACK, >=15 min capacity, survives outage + power loss. seq
    persisted across reboots for SBC idempotency. Host tests + stubs included.
    [spool.c]
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2026-06-11 firmware: raise Wi-Fi connect retries 4->20 (flaky-AP headroom)
    Consumer routers/hotspots reject the first several cyw43 join attempts
    (rc=-8 CONNECT_FAILED) and only accept after ~5 retries; 4 was too few and
    made sensor_module look 'hung' on assoc. Failed attempts return fast, so
    20 attempts at 1 s backoff connect reliably. Matches the proven bring-up.
    [app_config.h]
2026-06-11 firmware(env): subtract ~5C self-heating offset from temp_c
    The env sensor sits on the 3V3 rail next to the Pico/radar and reads ~5C
    high. Applied at the env_driver vtable read so it corrects AHT21 + BME280
    in both the production firmware and the bring-up. Constant
    ENV_TEMP_SELF_HEAT_OFFSET_C in env_driver.h, tunable per enclosure.
    Addresses supervisor feedback (temperature consistently 5C too hot).
    [aht21.c]
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2026-06-12 radar: decoupled repeating vitals estimate + HIL tuning; fix DNS dangling callback
    Radar plausibility filter (ADR-0005):
    - Port the supervisor's updated reference: absence window 2s->8s, breath
    -2 RPM calibration offset, and a robust median+MAD vitals estimate.
    - HIL-tune vital input timeouts heart 6s->15s, breath 6s->20s. The MR60BHA2
    reports heart and breath in long alternating bursts, so each vital must
    hold through the other's burst instead of expiring (verified on hardware).
    - Decouple the final estimate per vital: each fills its own 20s window over
    its own stable runs (simultaneous stability never lasted long enough on
    hardware - both-stable runs topped out ~8-29s). The estim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
    [radar_filter.h, transport_mqtt.c]
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2026-06-13 sensor_air(ENS160): fix compensation encoding overflow + debounce warm-up restart
    The TEMP_IN/RH_IN compensation registers were encoded Q8.8 (x256). x256
    overflows uint16 for any ambient above -17 C (19 C -> 292.15 K x256 = 74790,
    wraps to 9254), feeding the chip a garbage temperature that provoked the
    field STATUS=0x03 ("not operating") dropouts investigated 2026-06-12.
    - Encode per the ScioSense reference set_envdata: TEMP_IN = Kelvin x64 (u10.6),
    RH_IN = %rH x512 (u7.9); clamp temp to a sane ambient range before scaling.
    - Debounce the STATAS-clear recovery: re-writing OPMODE=STANDARD restarts the
    chip's warm-up, so reacting to a single transient STATAS-clear read turned a
    glitch i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
    [ens160.c]
2026-06-13 radar: live rolling-median vitals (<=10s refresh, presence-gated) + mirror clears
    Requirement (2026-06-12): stable, UPDATING heart/breath on the mirror at least
    every 10 s, and only while presence is detected. The hold-the-last-number
    approach couldn't deliver a *refreshing* value, and the reference's jump-guard
    + 10 s re-confirm kept creating the outages.
    Live display path redesigned:
    - Per vital, a 30 s ring of in-range raw readings; the published value is the
    ring MEDIAN, calibrated. Median is the stability mechanism (a ghost is
    outvoted, no re-confirm outage) and refreshes every publish (~1.3 s).
    - Shown after 5 readings (~5 s), carried to 25 s staleness, blanked on
    presence loss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
    [radar_filter.h]
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2026-06-14 radar: phase-based breath-hold detection (resp_motion, ADR-0006)
    Add a tri-state resp_motion field to the radar topic, derived on the MCU
    from the MR60BHA2 0x0A13 breath-phase amplitude. The windowed breath rate
    cannot fall during a hold, so this carries the hold signal the rate cannot:
    true = chest motion, false = possible breath-hold (breath_bpm nulled),
    null = undetermined. Fail-safe by construction.
    - radar_bha2: ring the breath phase, report peak-to-peak amplitude with a
    well-formed-window guard (min samples, freshness, span)
    - radar_filter: amplitude -> resp_motion with hysteresis thresholds
    - json_encode: emit resp_motion (-1/0/1 -> null/false/true)
    - radar_task: dev-console amp/ho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
    [radar_bha2.c, radar_filter.h, spool.c]
2026-06-14 radar: tune breath-hold thresholds + bringup encoder + clean diagnostics (ADR-0006)
    Follow-up to ef5e03e, which landed with placeholder thresholds and without
    the bringup radar encoder change (sensors_publish.c was not in that commit):
    - radar_filter: bench-tuned RADAR_HOLD_AMP_MIN/_RESUME 0.5/1.0 -> 3.0/5.0
    (live MR60BHA2: normal-breathing breath-phase p2p ~6-9, held ~0.5-1.6;
    validated on hardware - motion flips 1->0 on a hold, breath_bpm nulled)
    - sensors_publish (bringup/demo firmware path): emit resp_motion from its
    own radar encoder so the field reaches the wire; fold a hold indicator
    (motion=yes/HOLD, amp) into the radar log
    - radar_task: demote the tuning log to gated observ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
    [radar_filter.h]
2026-06-14 radar: two-tier live median — track rate changes in ~12s, not ~30s
    HIL: the MR60BHA2 reports breath/heart rates correctly (rawBR up to ~30
    RPM observed) but the 30 s display median lagged ~30 s behind a real
    change, so faster breathing barely moved the tile. Compute the displayed
    value over the last RADAR_LIVE_FAST_MS (12 s) when that recent window holds
    >= MIN_SAMPLES (responsive), falling back to the full 30 s ring during a
    burst gap so gap-survival/carry is preserved (alternation/staleness tests
    unchanged). Applies to both vitals.
    The residual fast-breathing ceiling (~25-30 RPM) is the module's
    respiration band, not our filter.
    - radar_filter: ring_live_median() two-tier; RADAR_LIVE_F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
    [radar_filter.h]
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2026-06-15 radar(hmmd): correct driver to the real Waveshare report-mode protocol
    The HMMD driver added in a6ec554 assumed the Seeed 0x53 0x59 / 0x54 0x43
    framing with presence/respiration/heart command frames. That was inference.
    The previous BAP group's working driver is in-repo
    (bestanden_vorige_BAP/.../lib/hmmd_mpy.py) and CLAUDE.md §18 designates it the
    behavioural spec — it pins the real part and protocol:
    Waveshare HMMD, "Report Mode":
    [F4 F3 F2 F1] [LEN (2B, little-endian)] payload [F8 F7 F6 F5]
    payload = presence(1) + distance(2, LE) + 16 x gate-energy(2, LE)
    no checksum; init must first send the Report-Mode command
    Crucially the HMMD is a presence + distance + motion radar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
    [board_pico2wh.h, radar_hmmd.c]
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2026-06-22 Revert "radar(bha2): phase-derived breath rate via Goertzel (ADR-0008)"
    This reverts commit 6329d47. On real (irregular) breathing the Goertzel phase
    estimator sub-harmonic-locks to ~half the true rate, reading worse than the
    module's own 0x0A14 BR it replaced. Reverted on hardware; radar back to the
    module BR. The estimator + ADR-0008 stay in history (6329d47) for a future
    fix — do not naively re-apply (sub-harmonic locking).
    [radar_bha2.c, radar_filter.h]
2026-06-22 fix(board): correct POWER/WIFI status-LED pins to match as-built PCB (ADR-0009)
    On the assembled PCB the two status LEDs are wired to the opposite pins. Swap
    BOARD_LED_POWER_PIN -> GP15 (pin 20) and BOARD_LED_WIFI_PIN -> GP14 (pin 19) so
    the firmware drives the correct LED for each state. All callers reference the
    LEDs only through these macros, so no other code changes are needed. pin_map.md
    synced; ADR-0009 records the board_pico2wh.h edit (CLAUDE.md §19).
    [board_pico2wh.h]
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2026-07-10 fix(sensor_air): ENS160 STATAS recovery debounce 2->15 reads + init start confirmation
    Bench evidence (2026-06-19): a genuine ENS160 alternates STATUS 0x89/0x01
    during warm-up; the old 2-read re-kick treated that as a stuck OPMODE and
    restarted the chip in a loop, which is what produced the all-zero readings.
    Debounce raised to 15 consecutive STATAS=0 reads before recovery (~15 s at
    1 Hz, up from ~2 s — deliberate), and init now polls STATAS up to ~3 s to
    confirm the sensor actually started. Host test updated to match; also wires
    the sensor_cal.h trim seam into this driver.
    [ens160.c]
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2026-07-10 fix(sensor_env)!: env part is BMP280 not BME280 — rename driver, nullable hum_pct
    The PCB's env footprint is populated with a Bosch BMP280 (chip ID 0x58:
    temp + pressure, NO humidity sensor), not the BME280 the previous group's
    docs claimed. Bench-verified. This commit makes the firmware tell the truth:
    - driver renamed bme280.[ch] -> bmp280.[ch]; types/symbols Bmp280*;
    BOARD_BMP280_ADDR; sensors.json env value "bmp280" (legacy "bme280"
    still accepted as an alias so provisioned devices keep booting)
    - hum_pct is now nullable on the wire, symmetric with the AHT21's null
    pres_hpa: EnvSample.humidity_valid, JSON encoder emits "hum_pct":null,
    OLED renders "H --"
    - BREAKING: spool reco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
    [aht21.c, app_main.c, bmp280.c]
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2026-07-11 docs+chore: fix the clarity findings from the structure audit
    Three independent fresh-eyes audits (newcomer walk, layout audit, docs-graph
    audit) rated the repo handover-ready but flagged a short list of real
    confusions; this commit fixes the substantive ones:
    - FIRST-FLASH FIX: CLAUDE.md §5 and docs/bring_up.md flash commands pointed
    at build/sensor_module.{uf2,elf}; the artifact actually lands in
    build/main/ — a newcomer's literal first command failed
    - CLAUDE.md self-contradictions reconciled with reality: §1 no longer claims
    the tablet/MM code lives in separate repos (now lists the companion docs),
    §3.4 pin-map path corrected to components/board/board_pico2wh.h, §6 test/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
    [Generic PCB.kicad_pcb, Generic PCB.kicad_sch, Mrror PCB.kicad_pcb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]
